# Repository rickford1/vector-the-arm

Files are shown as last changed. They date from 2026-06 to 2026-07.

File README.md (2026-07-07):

# Vector The Arm

Open-source 5-DOF printable robotic arm with vision-guided pick-and-place. Built on Feetech STS bus servos, ROS 2, MoveIt, and an Intel RealSense depth camera.

> **Status:** Work in progress. Mechanical assembly is complete (5-DOF arm +
> gripper). **All six servos are calibrated** and mirror live into RViz, and
> **MoveIt plans and executes on both the simulated and the real arm** — wrist
> roll and gripper included. Perception is not yet integrated.

## Features

- **5-DOF kinematic chain** + gripper
- **Smart serial bus servos** (Feetech STS3215) with position + current sensing for force-aware gripping
- **ROS 2 + MoveIt** motion planning — runs in simulation *and* drives the real arm
- **Live RViz mirroring** of the physical arm from the servo bus
- **Depth-camera perception** via Intel RealSense for vision-guided picking (planned)
- **Fully 3D-printable** structural parts

## Visualize the URDF

Requires ROS 2 Humble and the joint-slider GUI (one-time install):

```bash
sudo apt install ros-humble-joint-state-publisher-gui
```

Build the description package once, then launch RViz with joint sliders:

```bash
source /opt/ros/humble/setup.bash
cd ros2
colcon build --packages-select vector_the_arm_description
source install/setup.bash
ros2 launch vector_the_arm_description display.launch.py
```

Joint limits in the URDF are the calibrated ranges from
[docs/calibration_chart.md](docs/calibration_chart.md). If you edit the
URDF, re-run `colcon build` before launching by package name.

## Mirror the real arm in RViz

`scripts/arm_gui.py` owns the serial bus, publishes live encoder positions as
`/joint_states` (using `calibration.yaml` for the per-joint encoder→radian
mapping), and launches `robot_state_publisher` + RViz so the model tracks the
physical arm in real time. It also gives you per-joint sliders and an E-stop.

```bash
source /opt/ros/humble/setup.bash
source ros2/install/setup.bash          # so RViz can launch by package name
python3 scripts/arm_gui.py
```

Set `port:` in `calibration.yaml` to your bus device (e.g. `/dev/ttyACM0`).
Move the arm by hand (torque off) or drive joints from the GUI — RViz mirrors it.

## Motion planning with MoveIt

One-time install of MoveIt and ros2_control:

```bash
sudo apt install ros-humble-moveit ros-humble-ros2-control ros-humble-ros2-controllers
```

Build the MoveIt config once:

```bash
source /opt/ros/humble/setup.bash
cd ros2
colcon build --packages-select vector_the_arm_moveit_config
source install/setup.bash
```

### Simulation (mock hardware)

```bash
ros2 launch vector_the_arm_moveit_config demo.launch.py
```

Plans and executes against a simulated arm — no hardware needed. Good for
trying plans before running them on the real servos.

MoveIt has two planning groups: **`arm`** (Joint1–5) positions the wrist, and
**`Gripper`** (gripper_joint) opens/closes the jaw independently.

### Drive the real arm

`scripts/moveit_servo_bridge.py` is a `FollowJointTrajectory` action server that
replaces the mock hardware: it owns the serial bus, publishes `/joint_states`
from live encoder reads (so MoveIt's start state matches the real arm), and
streams planned trajectories to the servos — mapping radians→encoder and
**clamping every goal to each joint's `soft_min`/`soft_max`** via
`calibration.yaml`.

Run in two terminals, both with ROS + workspace sourced, arm powered:

```bash
# Terminal 1 — bridge (start first; takes the bus, enables torque holding the
# current pose, publishes joint states, serves the trajectory action)
python3 scripts/moveit_servo_bridge.py

# Terminal 2 — MoveIt (rsp + move_group + RViz, no mock hardware)
ros2 launch vector_the_arm_moveit_config bringup_real.launch.py
```

In the **MotionPlanning** panel the start state already matches the real arm.
Set a goal (Joints tab), **Plan**, then **Execute** — the servos follow.

**Safety:**
- Start with **Velocity Scaling 0.10** and small joint moves.
- Goals are clamped to soft limits, so a plan can't drive into a hard stop.
- **Ctrl+C the bridge terminal is the E-stop** — it disables torque on exit.

**Gripper on hardware:** the bridge serves a second `FollowJointTrajectory`
action for `Gripper_controller` (`gripper_joint`), so the **`Gripper`** planning
group opens/closes the real jaw too. Grip force is bounded by the servo torque
limit (addr 48) — set it with `scripts/set_torque_limit.py` before gripping
objects so a closed jaw doesn't overload the servo.

**5-DOF note:** the arm has 5 actuated joints (base yaw + 3 pitch + wrist roll) —
still under 6, so arbitrary full pose goals may not solve. Use **joint-space** or
**position-only** goals.

**Regenerating the MoveIt config:** the Setup Assistant writes integer values
into `config/joint_limits.yaml` (move_group needs doubles, e.g. `2.0`) and omits
`action_ns: follow_joint_trajectory` on controllers — fix both after generating
or move_group won't start / finds "0 controllers".

## Documentation

- [CALIBRATION.md](CALIBRATION.md) — end-to-end servo calibration procedure

## Repo layout

```
scripts/    Servo SDK tools, calibration utilities (incl. grip-force limiter
            set_torque_limit.py), manual-control + live-mirror GUI, and the
            MoveIt→Feetech trajectory bridge
ros2/       ROS 2 packages:
              vector_the_arm_description   URDF, meshes, display launches
              vector_the_arm_moveit_config MoveIt config (SRDF, controllers,
                                           demo + real-hardware bringup)
docs/       Reference data (calibration chart, per-joint parameters)
cad/        CAD source files (forthcoming)
```

## License

TBD

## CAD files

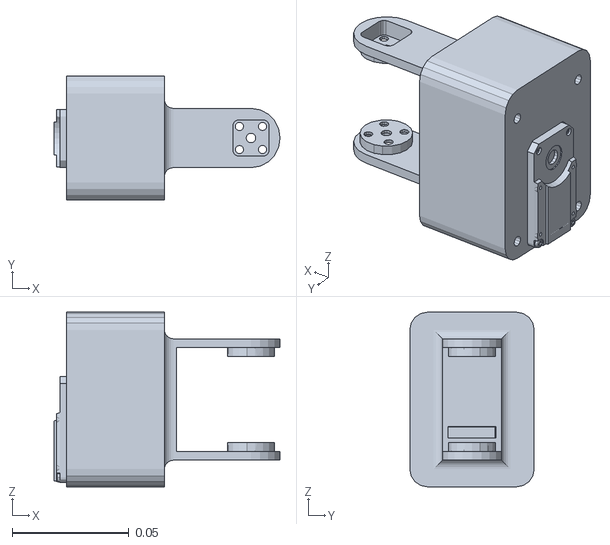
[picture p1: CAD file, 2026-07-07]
ros2/src/vector_the_arm_description/meshes/Link4.STL
0.0969 x 0.0533 x 0.0749

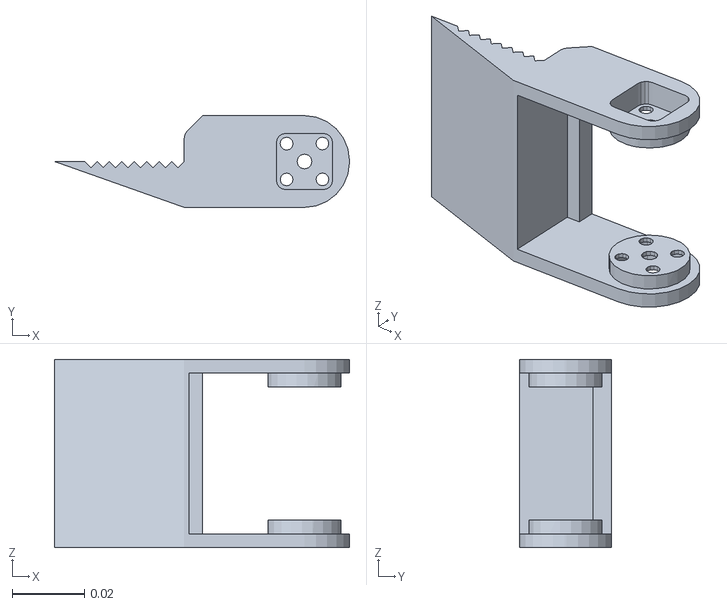
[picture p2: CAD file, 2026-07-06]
ros2/src/vector_the_arm_description/meshes/gripper.STL
0.0816 x 0.0254 x 0.0521

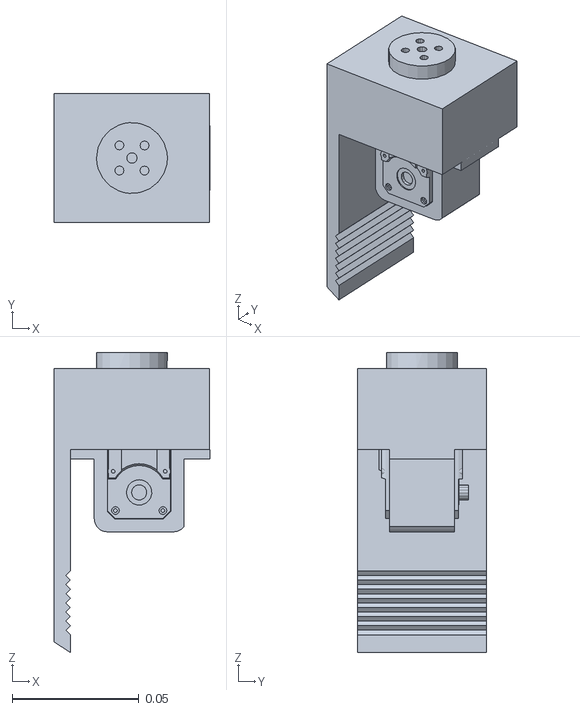
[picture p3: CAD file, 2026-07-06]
ros2/src/vector_the_arm_description/meshes/Link5.STL
0.0612 x 0.0508 x 0.118

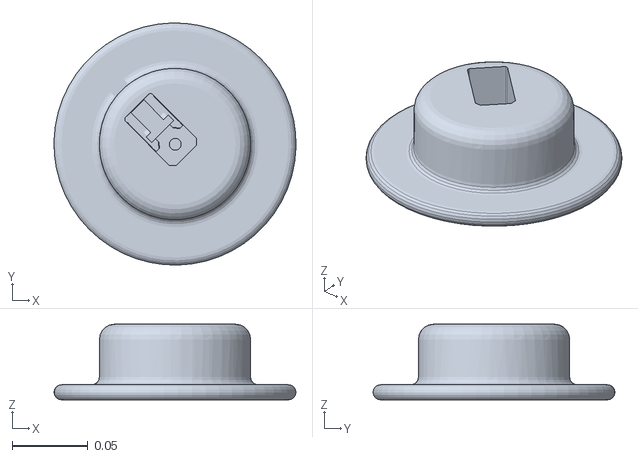
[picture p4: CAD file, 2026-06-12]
ros2/src/vector_the_arm_description/meshes/base_link.STL
0.16 x 0.16 x 0.05

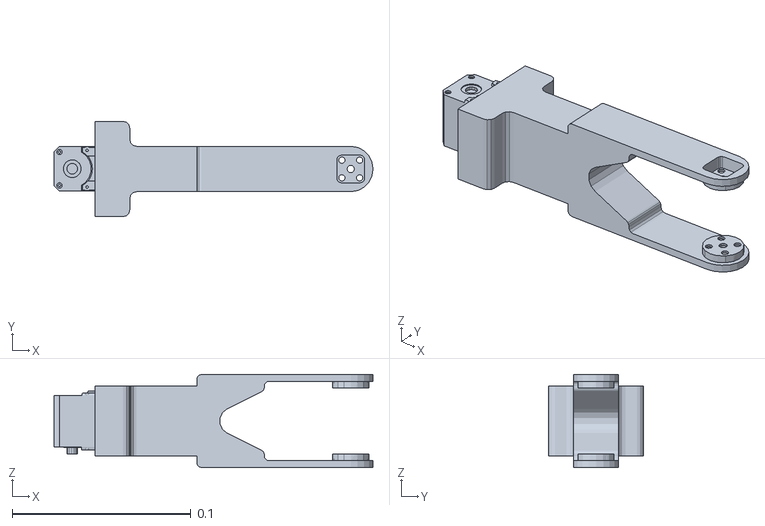
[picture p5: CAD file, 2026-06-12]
ros2/src/vector_the_arm_description/meshes/Link3.STL
0.179 x 0.0533 x 0.0521

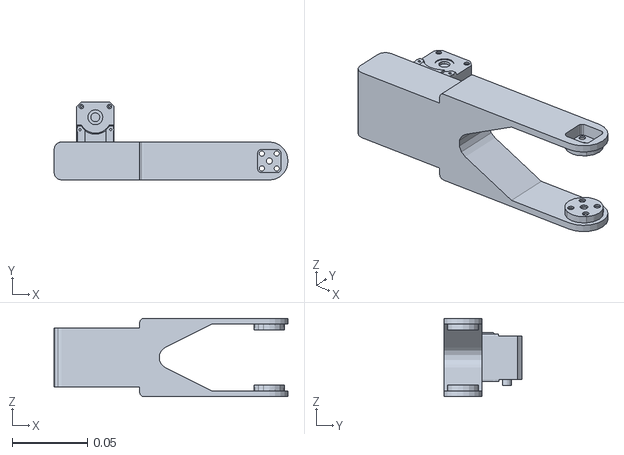
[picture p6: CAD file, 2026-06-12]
ros2/src/vector_the_arm_description/meshes/Link2.STL
0.156 x 0.052 x 0.0521

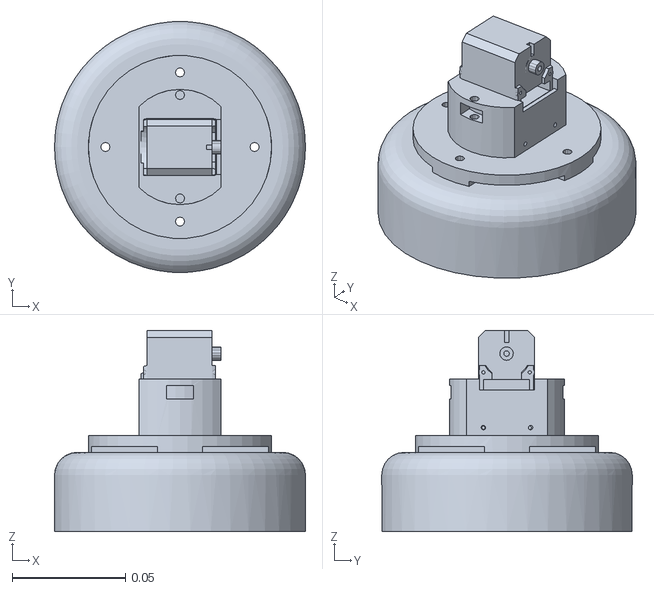
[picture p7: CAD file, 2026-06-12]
ros2/src/vector_the_arm_description/meshes/Link1.STL
0.111 x 0.111 x 0.0889

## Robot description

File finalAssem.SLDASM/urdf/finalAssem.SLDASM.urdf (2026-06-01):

<?xml version="1.0" encoding="utf-8"?>
<!-- This URDF was automatically created by SolidWorks to URDF Exporter! Originally created by Stephen Brawner (brawner@gmail.com) 
     Commit Version: 1.6.0-1-g15f4949  Build Version: 1.6.7594.29634
     For more information, please see http://wiki.ros.org/sw_urdf_exporter -->
<robot name="finalAssem.SLDASM">
  <link name="base_link">
    <inertial>
      <origin xyz="0.04017 0.036228 0.089961" rpy="0 0 0" />
      <mass value="0.47301" />
      <inertia ixx="0.00060925" ixy="-6.5656E-06" ixz="-2.5475E-09" iyy="0.00099286" iyz="2.1203E-09" izz="0.00059369" />
    </inertial>
    <visual>
      <origin xyz="0 0 0" rpy="0 0 0" />
      <geometry>
        <mesh filename="package://finalAssem.SLDASM/meshes/base_link.STL" />
      </geometry>
      <material name="">
        <color rgba="1 1 1 1" />
      </material>
    </visual>
    <collision>
      <origin xyz="0 0 0" rpy="0 0 0" />
      <geometry>
        <mesh filename="package://finalAssem.SLDASM/meshes/base_link.STL" />
      </geometry>
    </collision>
  </link>
  <link name="Link1">
    <inertial>
      <origin xyz="0 0 0.021148" rpy="0 0 0" />
      <mass value="0.078819" />
      <inertia ixx="0.00010458" ixy="0" ixz="-5.3187E-21" iyy="0.00010458" iyz="-1.4648E-20" izz="0.00019044" />
    </inertial>
    <visual>
      <origin xyz="0 0 0" rpy="0 0 0" />
      <geometry>
        <mesh filename="package://finalAssem.SLDASM/meshes/Link1.STL" />
      </geometry>
      <material name="">
        <color rgba="1 1 1 1" />
      </material>
    </visual>
    <collision>
      <origin xyz="0 0 0" rpy="0 0 0" />
      <geometry>
        <mesh filename="package://finalAssem.SLDASM/meshes/Link1.STL" />
      </geometry>
    </collision>
  </link>
  <joint name="Joint1" type="revolute">
    <origin xyz="0.039158 -0.09063 0.038393" rpy="0 0 0.78837" />
    <parent link="base_link" />
    <child link="Link1" />
    <axis xyz="0 0 0" />
    <limit lower="0" upper="0" effort="0" velocity="0" />
  </joint>
  <link name="Link2">
    <inertial>
      <origin xyz="0.049091 0.01203 -0.022092" rpy="0 0 0" />
      <mass value="0.089999" />
      <inertia ixx="2.8107E-05" ixy="-1.8894E-06" ixz="3.2642E-07" iyy="0.0001335" iyz="-9.2084E-08" izz="0.00011537" />
    </inertial>
    <visual>
      <origin xyz="0 0 0" rpy="0 0 0" />
      <geometry>
        <mesh filename="package://finalAssem.SLDASM/meshes/Link2.STL" />
      </geometry>
      <material name="">
        <color rgba="1 1 1 1" />
      </material>
    </visual>
    <collision>
      <origin xyz="0 0 0" rpy="0 0 0" />
      <geometry>
        <mesh filename="package://finalAssem.SLDASM/meshes/Link2.STL" />
      </geometry>
    </collision>
  </link>
  <joint name="Joint2" type="revolute">
    <origin xyz="-0.023218 0.012518 0.21186" rpy="3.1416 1.5708 0" />
    <parent link="Link1" />
    <child link="Link2" />
    <axis xyz="0 0 0" />
    <limit lower="0" upper="0" effort="0" velocity="0" />
  </joint>
  <link name="Link3">
    <inertial>
      <origin xyz="0.042349 0.012701 -0.022133" rpy="0 0 0" />
      <mass value="0.10792" />
      <inertia ixx="3.8564E-05" ixy="2.0743E-08" ixz="4.1708E-07" iyy="0.00015487" iyz="6.9966E-10" izz="0.00014301" />
    </inertial>
    <visual>
      <origin xyz="0 0 0" rpy="0 0 0" />
      <geometry>
        <mesh filename="package://finalAssem.SLDASM/meshes/Link3.STL" />
      </geometry>
      <material name="">
        <color rgba="1 1 1 1" />
      </material>
    </visual>
    <collision>
      <origin xyz="0 0 0" rpy="0 0 0" />
      <geometry>
        <mesh filename="package://finalAssem.SLDASM/meshes/Link3.STL" />
      </geometry>
    </collision>
  </link>
  <joint name="Joint3" type="revolute">
    <origin xyz="-0.11579 0.029138 0.00049896" rpy="0 0 0" />
    <parent link="Link2" />
    <child link="Link3" />
    <axis xyz="0 0 0" />
    <limit lower="0" upper="0" effort="0" velocity="0" />
  </joint>
  <link name="Link4">
    <inertial>
      <origin xyz="0.079969 0.012699 -0.019217" rpy="0 0 0" />
      <mass value="0.14858" />
      <inertia ixx="0.00010827" ixy="6.8754E-09" ixz="4.5551E-06" iyy="0.0001079" iyz="3.3593E-10" izz="7.5944E-05" />
    </inertial>
    <visual>
      <origin xyz="0 0 0" rpy="0 0 0" />
      <geometry>
        <mesh filename="package://finalAssem.SLDASM/meshes/Link4.STL" />
      </geometry>
      <material name="">
        <color rgba="1 1 1 1" />
      </material>
    </visual>
    <collision>
      <origin xyz="0 0 0" rpy="0 0 0" />
      <geometry>
        <mesh filename="package://finalAssem.SLDASM/meshes/Link4.STL" />
      </geometry>
    </collision>
  </link>
  <joint name="Joint4" type="revolute">
    <origin xyz="-0.15595 0.025556 -0.043973" rpy="3.1416 0 0" />
    <parent link="Link3" />
    <child link="Link4" />
    <axis xyz="0 0 0" />
    <limit lower="0" upper="0" effort="0" velocity="0" />
  </joint>
</robot>

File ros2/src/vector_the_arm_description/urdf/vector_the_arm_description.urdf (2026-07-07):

<?xml version="1.0" encoding="utf-8"?>
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
<robot name="vector_the_arm_description">
  <link name="base_link">
    <inertial>
      <origin xyz="0.0011876 -0.00024586 -0.0021651" rpy="0 0 0" />
      <mass value="0.47301" />
      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
    </inertial>
    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
  </link>
  <link name="Link1">
    <inertial>
      <origin xyz="-0.00013887 -3.7112E-05 0.037653" rpy="0 0 0" />
      <mass value="0.16671" />
      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
    </inertial>
    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
  </link>
  <joint name="Joint1" type="revolute">
    <origin xyz="0 0 0" rpy="0 0 3.1416" />
    <parent link="base_link" />
    <child link="Link1" />
    <axis xyz="0 0 1" />
    <limit lower="-1.5708" upper="1.5708" effort="3.0" velocity="2.0" />
  </joint>
  <link name="Link2">
    <inertial>
      <origin xyz="-0.09422 0.003695 -0.022118" rpy="0 0 0" />
      <mass value="0.12354" />
      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
    </inertial>
    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
  </link>
  <joint name="Joint2" type="revolute">
    <origin xyz="-0.023219 -0.000282 0.07716" rpy="3.1416 1.5708 0" />
    <parent link="Link1" />
    <child link="Link2" />
    <axis xyz="0 0 1" />
    <limit lower="-1.82" upper="1.82" effort="3.0" velocity="2.0" />
  </joint>
  <link name="Link3">
    <inertial>
      <origin xyz="-0.104627 -0.000063 -0.022151" rpy="0 0 0" />
      <mass value="0.14146" />
      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
    </inertial>
    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
  </link>
  <joint name="Joint3" type="revolute">
    <origin xyz="-0.11579 0.029138 0.00049896" rpy="0 0 0" />
    <parent link="Link2" />
    <child link="Link3" />
    <axis xyz="0 0 1" />
    <limit lower="-1.60" upper="1.60" effort="3.0" velocity="2.0" />
  </joint>
  <link name="Link4">
    <inertial>
      <origin xyz="-0.057402 -0.000135 -0.022293" rpy="0 0 0" />
      <mass value="0.18212" />
      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
    </inertial>
    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
  </link>
  <joint name="Joint4" type="revolute">
    <origin xyz="-0.15595 -0.000044 -0.043973" rpy="3.1416 0 0" />
    <parent link="Link3" />
    <child link="Link4" />
    <axis xyz="0 0 -1" />
    <limit lower="-1.55" upper="1.55" effort="3.0" velocity="2.0" />
  </joint>
  <link name="Link5">
    <inertial>
      <origin xyz="-0.0037812 -7.5442E-05 0.0098443" rpy="0 0 0" />
      <mass value="0.15471" />
      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
    </inertial>
    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
  </link>
  <joint name="Joint5" type="continuous">
    <origin xyz="-0.1347 -0.000286 -0.022559" rpy="1.5708 0 1.5708" />
    <parent link="Link4" />
    <child link="Link5" />
    <axis xyz="0 0 1" />
  </joint>
  <link name="gripper">
    <inertial>
      <origin xyz="-0.039632 -0.0052695 0.00073607" rpy="0 0 0" />
      <mass value="0.020259" />
      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
    </inertial>
    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
  </link>
  <joint name="gripper_joint" type="revolute">
    <origin xyz="0.002823 0 -0.008531" rpy="1.5708 -1.5708 0" />
    <parent link="Link5" />
    <child link="gripper" />
    <axis xyz="0 0 1" />
    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
    <limit lower="-0.468" upper="1.658" effort="1.0" velocity="1.0" />
  </joint>
</robot>

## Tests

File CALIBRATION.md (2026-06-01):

# Robot Arm Servo Calibration Guide

End-to-end calibration procedure for a Feetech STS3215-based robot arm. This is the procedure used to bring this arm from a box of parts to a fully-calibrated 5-DOF + gripper system ready for ROS 2 / MoveIt. Reading time ~15 min. Working time ~1–2 hours for a 4–6 joint arm.

## What "calibration" means here

For each servo, calibration produces four things stored in `calibration.yaml`:

1. **A unique bus ID** — so multi-drop bus addressing works
2. **A known horn orientation** — encoder pos 2048 corresponds to a known physical pose ("neutral")
3. **Mechanical range** — the encoder min/max for the joint's physical travel between hard stops
4. **Soft limits** — software-enforced bounds inside the mechanical range, with a safety margin

Plus, if needed: a **Position Correction** value written to EEPROM to fix encoder wraparound (when a joint's travel crosses encoder 0/4095).

The result: every script and ROS node in this project knows where each joint is in physical space and what range it can safely move through.

---

## Prerequisites

### Hardware

- Feetech STS3215 servos (any quantity; tested with 6)
- Waveshare bus servo driver board (or equivalent USB-to-TTL bus adapter)
- 12 V DC power supply, **≥5 A recommended** (10 A for stalling margin)
- USB cable to driver board
- Servos pre-assembled into arm (or bench setup if pre-assembly)

### Software

```bash
pip install feetech-servo-sdk pyyaml
```

This project uses the lower-level `protocol_packet_handler` API (the higher-level `sms_sts` class is not in the PyPI package — don't try to import it).

### Permissions

You'll need access to the serial device:

```bash
sudo usermod -a -G dialout $USER
# log out and back in
```

Otherwise, every script will fail with permission errors on `/dev/ttyACM*`.

### Find your bus device

```bash
ls /dev/ttyACM* /dev/ttyUSB*
```

Most setups show `/dev/ttyACM0`. The Waveshare board uses USB CDC-ACM, so it's `ttyACM*`, not `ttyUSB*`. **Note**: the number can shuffle between reboots — see [Troubleshooting → Port Shuffling](#port-shuffling) for a permanent fix.

### ⚠️ Verify PSU voltage before any servo work

STS3215 absolute max is ~14 V. Some "12 V" supplies (especially adjustable lab supplies and cheap bricks) drift high. **Check with a multimeter before plugging in servos.** A 14+ V supply will damage servos over time.

---

## The procedure

### Phase 1 — Assign unique IDs (one servo at a time)

**Every Feetech servo ships with factory ID = 1.** Plugging multiple new servos onto the same bus causes ID collisions: both servos respond to every ping simultaneously, the protocol corrupts, and you get inconsistent or no responses.

**Always assign IDs one servo at a time on an otherwise empty bus.**

For each servo:

1. **Power down** the bus (turn off the 12 V supply for safety, even though it's not strictly required for ID changes)
2. **Disconnect all other servos** from the bus. Leave only the servo you're about to flash.
3. **Power on**, then run:
   ```bash
   python3 scripts/scan.py --port /dev/ttyACM0 --max-id 10
   ```
   Confirm: only ID 1 responds (the factory default of the lone servo).
4. **Flash to the target ID**:
   ```bash
   python3 scripts/servo_id_setup.py --port /dev/ttyACM0 --new-id <N>
   ```
   Where `<N>` is the desired ID (1–253). For an arm, use sequential IDs starting at 1 from base to gripper.
5. **Verify**:
   ```bash
   python3 scripts/scan.py --port /dev/ttyACM0 --max-id 10
   ```
   Should now show only ID `<N>`.
6. **Power down**, disconnect this servo, connect the next factory-fresh one, repeat.

After all servos are flashed: power down, connect the full daisy chain (or split across both ports if your bus board has two), power up, and run the full scan. You should see every assigned ID respond.

> **If you see a collision** (servos showing intermittently or missing): one of your servos is at the same ID as another. Disconnect the most recently added one and the original should reappear. See [Troubleshooting → Bus collision recovery](#bus-collision-recovery).

> **If you accidentally renamed the wrong servo** (very easy mistake): the script defaults to `--current-id 1`. If you ran it on a populated bus, the script targeted whichever servo was at ID 1 — often the wrong one. Recover by disconnecting all but the renamed servo, identifying its current ID with `scan.py`, then using `--current-id <wrong_id> --new-id <correct_id>` to rename it back.

### Phase 2 — Mount horns at the calibration reference position

For each servo, we want **encoder pos 2048** (the middle of the encoder's 0–4095 range) to correspond to a known physical pose — usually the midpoint of the joint's mechanical travel for a bounded joint, or "facing forward" for a continuous-rotation base joint.

This isn't pixel-perfect: STS3215 has a 25-tooth output spline (~14.4° between mountable horn positions), so you'll mount as close as the spline allows and absorb the remaining offset in software.

For each servo:

1. **Drive to encoder pos 2048** with torque holding:
   ```bash
   python3 scripts/set_pos.py --port /dev/ttyACM0 --id <N> --pos 2048
   ```
   The script keeps torque on after the move so the shaft stays put while you align the horn.

2. **Mount the horn** at the closest spline position to the desired physical neutral. For a bounded joint, eyeball/measure the midpoint between the two mechanical hard stops. For the base joint (continuous), pick a "facing forward" or "joint angle 0" orientation that matches your kinematic convention.

3. **Tighten the horn screw firmly** before releasing torque — a loose horn slips under load, shifting your calibration.

4. **Release torque**:
   ```bash
   python3 scripts/relax.py --id <N>
   ```

5. Optionally photograph each horn orientation for future reference.

> For an arm assembled around already-mounted servos, you can skip this phase if the horns are already at sensible positions — Phase 3 (range capture) and Phase 4 (correction) handle any offset in software.

### Phase 3 — Capture mechanical range per joint

With horns mounted and the arm assembled, capture each joint's mechanical limits by hand-rotating between its hard stops:

For each joint:

1. **Release torque** (so you can rotate by hand):
   ```bash
   python3 scripts/relax.py --id <N>
   ```

2. **Start the recorder**:
   ```bash
   python3 scripts/range_record.py --port /dev/ttyACM0 --id <N>
   ```

3. **Hand-rotate the joint deliberately**:
   - Slowly to one hard stop, pause for ~1 second
   - Slowly back through center to the other hard stop, pause for ~1 second
   - Slowly to center

4. **Press Ctrl+C** to print the summary.

The summary shows `min`, `max`, `range`, and `center` in encoder steps and degrees.

> **Continuous-rotation joints** (e.g., base joints with slip rings or no hard stops): the recorded "range" will be ~360° because the joint can spin freely. Note these as `type: continuous` in `calibration.yaml`, and define software soft limits (typically ±180° from your chosen zero) to prevent wire twist.

### Phase 4 — Fix encoder wraparound (when needed)

If `range_record.py` reports a range close to **360° (min near 0, max near 4095)** on a joint that **physically cannot rotate that much**, the joint's mechanical range is crossing the encoder's 0↔4095 boundary. The encoder counts up to 4095, wraps to 0, and continues — making the recording show the full 0–4095 span even though the actual physical travel is smaller.

The fix: shift the encoder's reading via the **Position Correction register** (EEPROM addr 31) so the joint's range fits cleanly within 0–4095.

For each affected joint:

1. **Hand-rotate the joint to its physical midpoint** between the two hard stops (by feel, no software needed).

2. **Run the correction**:
   ```bash
   python3 scripts/set_correction.py --port /dev/ttyACM0 --id <N> --target 2048
   ```
   This reads the current encoder value, computes the offset needed to make this pose read 2048, and writes it to EEPROM. You'll be prompted to confirm (type `y`).

3. **Re-run `range_record.py`** to verify a clean range:
   ```bash
   python3 scripts/range_record.py --port /dev/ttyACM0 --id <N>
   ```
   Should now show a sensible physical range (e.g. 1029–3059, ~178°) with `min` and `max` both well clear of 0 and 4095.

> **Critical rule**: only run `set_correction.py` when wraparound is *actually present*. If `range_record.py` already shows a clean range, do not run it — applying an unnecessary correction can create a wraparound where there wasn't one.

### Phase 5 — Save the calibration data

Update `calibration.yaml` with each joint's results. Template:

```yaml
port: /dev/ttyACM0
baud: 1000000

servos:
  - id: 1
    joint_name: base
    type: continuous           # or "bounded" for joints with hard stops
    encoder_min: 0             # for continuous, use full encoder range
    encoder_max: 4095
    encoder_center: 2048       # from range_record summary
    soft_min: 1024             # for continuous, set ±90° from center initially
    soft_max: 3072
    position_correction: 0     # if no correction was applied
    direction: 1               # +1 or -1, depending on URDF convention
    model: 777
    notes: continuous rotation; soft-limited to ±90° to avoid wire twist

  - id: 2
    joint_name: joint2
    type: bounded
    encoder_min: 902           # from range_record "min"
    encoder_max: 3280          # from range_record "max"
    encoder_center: 2091       # from range_record "center"
    soft_min: 952              # add 50-step margin from hard stops
    soft_max: 3230
    position_correction: -1937 # informational; actual value lives in servo EEPROM
    direction: 1
    model: 2825                # firmware variants exist; harmless
    notes: 209° range
```

The `soft_min` / `soft_max` values are what the GUI and ROS bridge use as bounds. Default to a ~50-step margin (~4°) inside the hard stops to prevent driving the joint into a physical stop under torque.

### Phase 6 — Verify with the GUI

```bash
python3 scripts/arm_gui.py
```

A window opens with one row per servo: live position display, slider bounded by soft limits, per-joint torque toggle, and global E-STOP. For each calibrated joint:

1. **Enable torque** via the checkbox
2. **Move the slider** slowly — the joint should smoothly track the slider value
3. **Watch the live position** — should match the slider value within a few steps
4. **Try the endpoints** of the slider — joint should reach near the soft limits without straining
5. **Hit E-STOP** at any point to release torque on all joints

If a joint strains, fights the slider, or refuses to move, see [Troubleshooting](#troubleshooting).

When you close the window, all torque is released automatically.

---

## Troubleshooting

### Port shuffling

The `/dev/ttyACM*` number can change between reboots (e.g., `ttyACM0` becomes `ttyACM2`). Permanent fix via a udev rule:

1. Find the board's USB IDs:
   ```bash
   udevadm info -a -n /dev/ttyACM0 | grep -E 'idVendor|idProduct' | head -4
   ```

2. Create `/etc/udev/rules.d/99-feetech.rules`:
   ```
   SUBSYSTEM=="tty", ATTRS{idVendor}=="XXXX", ATTRS{idProduct}=="YYYY", SYMLINK+="feetech-bus", MODE="0666"
   ```

3. Reload:
   ```bash
   sudo udevadm control --reload-rules
   sudo udevadm trigger
   ```

Now `/dev/feetech-bus` always points to your board. Set `port: /dev/feetech-bus` in `calibration.yaml`.

### Bus collision recovery

If two servos end up at the same ID, neither will respond cleanly (both try to answer every ping → protocol corruption → timeout).

1. **Disconnect one of the colliding servos** physically — usually the one you most recently added.
2. **Scan the remaining bus**:
   ```bash
   python3 scripts/scan.py --port /dev/ttyACM0 --max-id 10
   ```
   The remaining servo should now respond at the disputed ID.
3. **Rename it** to its proper ID:
   ```bash
   python3 scripts/servo_id_setup.py --port /dev/ttyACM0 --current-id <wrong> --new-id <correct>
   ```
4. **Reconnect the other servo** alone on the bus (without the first one) and flash it to its correct ID.
5. **Reconnect everything**, scan again to verify.

### Voltage error (status byte = 1)

If `diag.py` reports `Status byte: 1 ['voltage']`, the servo's firmware detected over-voltage. Check the PSU output with a multimeter:

- Should read **12.0 V ± 0.3 V**
- 13 V or higher: dial down the supply (if adjustable) or replace it (if fixed). 14+ V will damage servos cumulatively.

### Joint strains / moves slowly

This happens when the servo is fighting a load it doesn't have enough torque for — common on base joints supporting the full arm mass. Distinguish from a faulty servo:

1. **Run `diag.py`** — verify Mode is 0 (position), torque limit is 1000/1000, status byte is 0 (no errors)
2. **Bench-test off the arm**: unbolt the servo and run `nudge.py` with no load
   - If it moves cleanly → arm load is the issue (mechanical, not the servo)
   - If it still strains → real servo issue (gear damage, low PSU current, voltage sag under load)

Common arm-load fixes: lighter end-effector, more PSU current capacity, mechanical advantage in design (gear reduction, counterbalance).

### "No response" on a known-good servo

- **Power cycle the 12 V supply** — servo firmware can hang
- **Verify the bus connection** — daisy-chain connectors are easy to dislodge
- **Try a different baud** with `scan.py` — defaults to 1 Mbaud but factory or modified servos may be different

---

## Script reference

| Script | Purpose | Modifies hardware? |
|---|---|---|
| `scan.py` | Sweep IDs at all common baud rates, list found servos | Read-only |
| `status.py` | Show position / voltage / temperature for given IDs | Read-only |
| `diag.py` | Full per-servo state snapshot | Read-only |
| `servo_id_setup.py` | Change a servo's bus ID (EEPROM write) | Yes — EEPROM |
| `set_pos.py` | Drive a servo to a target encoder position, keeps torque on | Yes — torque + motion |
| `nudge.py` | Small relative move from current position | Yes — torque + motion |
| `relax.py` | Disable torque on one or many servos | Yes — torque off |
| `range_record.py` | Disable torque, log min/max during hand rotation | Yes — torque off |
| `set_correction.py` | Write Position Correction register (EEPROM) to shift encoder readout | Yes — EEPROM |
| `arm_gui.py` | Interactive GUI for manual joint control within soft limits | Yes — torque + motion (user-controlled) |

All scripts accept `--port <device>` (default `/dev/ttyACM0`) and `--id <N>` where applicable. Run any with `--help` for full argument list.

---

## What's next

After calibration is complete and verified with the GUI:

1. **Build the URDF** from your CAD assembly (or the included `urdf/` files if cloning this repo)
2. **Build the ROS 2 bridge node** that translates between `sensor_msgs/JointState` topics and the Feetech bus, using `calibration.yaml` for per-joint scale/offset/limits
3. **Integrate with MoveIt** for motion planning
4. **Add perception** (e.g., RealSense + object detection) for vision-guided tasks

Each of these is covered in separate guides (`URDF.md`, `ROS2_BRIDGE.md`, `MOVEIT.md`, `PERCEPTION.md`). The calibration data you generated here flows through all of them.

---

## Open questions / known caveats

- **Continuous-rotation joints** need software multi-turn tracking if you want to count revolutions, or soft limits at ±180° to avoid wraparound during operation.
- **Position Correction values are informational in `calibration.yaml`** — the actual correction lives in servo EEPROM. Editing the YAML doesn't change the servo's behavior; use `set_correction.py` to update it.
- **Direction sign per joint** is left as `TBD` until the URDF is built — it depends on your kinematic frame conventions. Easily flipped later in `calibration.yaml`.
- **Motor mass for accurate dynamics**: STS3215 datasheet says ~60 g. For Gazebo simulation or dynamics-aware planning, override mass in your CAD before exporting the URDF; the raw STEP file usually computes wrong from solid-density math.

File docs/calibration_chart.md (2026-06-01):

# Servo Calibration

Reference pos: `2048` (encoder midpoint) for all servos.
Bus: `/dev/ttyACM0`, baud `1000000`, protocol STS.

## Per-servo calibration

| ID | Joint | Model | Range type | Mounted at | Min (steps) | Max (steps) | Range (steps) | Range (deg) | Mech midpoint (steps) | Offset from 2048 | Direction | Notes |
|----|---|---|---|---|---|---|---|---|---|---|---|---|
| 1  | base | 777  | continuous | 2048 | n/a | n/a | n/a | n/a | 2044 (centered) | -4 | TBD | **continuous rotation — no hard stops**. Horn well-centered (offset -4). Need software multi-turn tracking or soft limits at e.g. ±180° from 2048. |
| 2  | (joint?) | 2825 | 209° | 2048 | 902 | 3280 | 2378 | 209.0 | 2091 | +43 | TBD | model 2825 variant. Position Correction set via set_correction.py; raw was crossing 0/4095 boundary |
| 3  | (joint?) | 777  | 183° | 2048 | 981 | 3064 | 2083 | 183.1 | 2022 | -26 | TBD | recalibrated post-reassembly; existing Position Correction retained; clean range |
| 4  | joint4 | 777  | 178° | 2048 | 1029 | 3059 | 2030 | 178.4 | 2044 | -4 | TBD | additional arm joint; clean range, Position Correction set |
| 5  | wrist_roll | 777  | TBD  | TBD  | --- | --- | --- | --- | --- | --- | TBD | new servo, ID flashed; bare on bench; calibrate when wrist roll module is built |
| 6  | gripper | TBD  | TBD  | TBD  | --- | --- | --- | --- | --- | --- | TBD | not yet purchased; will be 6th servo |

## Field meanings

- **Mounted at**: encoder pos the horn was aligned at during calibration (always 2048 here)
- **Min / Max (steps)**: encoder values at each mechanical hard stop, captured via `range_record.py`
- **Range (steps)**: max − min
- **Range (deg)**: range × (360 / 4096)
- **Mech midpoint (steps)**: (min + max) / 2 — the true physical midpoint, in encoder steps
- **Offset from 2048**: mech_midpoint − 2048 — how far the actual midpoint sits from the nominal reference. Goes into the per-joint software calibration as `encoder_zero`.
- **Direction**: +1 or -1 — sign of joint angle relative to increasing encoder position (decide per joint based on your URDF / right-hand-rule convention)

## Verification notes per servo

- **ID 1** — comms OK (model 777), bench-test clean unloaded. Strained when mounted under arm load (expected for base joint).
- **ID 2** — comms OK (model **2825** — variant), nudge ±17° clean (err -3 / +0).
- **ID 3** — comms OK (model 777), motion test deferred (was electrically pinned near top of range, only ~1° of room in mechanically-free direction).
- **ID 4** — comms OK (model 777), nudge -20° clean (err +15 / -1).

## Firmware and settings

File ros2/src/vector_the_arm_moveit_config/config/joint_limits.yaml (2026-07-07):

# joint_limits.yaml allows the dynamics properties specified in the URDF to be overwritten or augmented as needed

# For beginners, we downscale velocity and acceleration limits.
# You can always specify higher scaling factors (<= 1.0) in your motion requests.  # Increase the values below to 1.0 to always move at maximum speed.
default_velocity_scaling_factor: 0.1
default_acceleration_scaling_factor: 0.1

# Specific joint properties can be changed with the keys [max_position, min_position, max_velocity, max_acceleration]
# Joint limits can be turned off with [has_velocity_limits, has_acceleration_limits]
joint_limits:
  Joint1:
    has_velocity_limits: true
    max_velocity: 2.0
    has_acceleration_limits: false
    max_acceleration: 0.0
  Joint2:
    has_velocity_limits: true
    max_velocity: 2.0
    has_acceleration_limits: false
    max_acceleration: 0.0
  Joint3:
    has_velocity_limits: true
    max_velocity: 2.0
    has_acceleration_limits: false
    max_acceleration: 0.0
  Joint4:
    has_velocity_limits: true
    max_velocity: 2.0
    has_acceleration_limits: false
    max_acceleration: 0.0
  Joint5:
    has_velocity_limits: false
    max_velocity: 0.0
    has_acceleration_limits: false
    max_acceleration: 0.0
  gripper_joint:
    has_velocity_limits: true
    max_velocity: 1.0
    has_acceleration_limits: false
    max_acceleration: 0.0

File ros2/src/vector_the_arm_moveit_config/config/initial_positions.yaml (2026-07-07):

# Default initial positions for vector_the_arm_description's ros2_control fake system

initial_positions:
  Joint1: 0
  Joint2: 0
  Joint3: 0
  Joint4: 0
  Joint5: 0
  gripper_joint: 0

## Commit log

2026-06-01 Add finalAssem.SLDASM URDF package
    [Link1.STL, Link2.STL, Link3.STL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]
2026-06-01 Rename package to vector_the_arm_description (ROS-valid name)
    [vector_the_arm_description.csv, vector_the_arm_description.urdf]
2026-06-01 create proper folder and repo structure along with refactor for improved readability
    [Link1.STL, Link2.STL, Link3.STL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]
2026-06-12 improve readme and update the urdf to better represent the cad
    [Link1.STL, Link2.STL, Link3.STL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]
2026-06-12 update urdf and cad stl files to include motor positions
    [Link1.STL, Link2.STL, Link3.STL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]
2026-07-02 update joint state publisher and gui to run with simulated model and physical model at the same time WIP
    [calibration.yaml, vector_the_arm_description.urdf]
2026-07-02 integrate moveit configuration for simulated enviorment
    [joint_limits.yaml, ros2_controllers.yaml, vector_the_arm_description.ros2_control.xacro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]
2026-07-06 Add MoveIt servo bridge and YOLO object detection scripts
    - Introduced `bringup_real.launch.py` to launch MoveIt with real hardware.
    - Added `moveit_servo_bridge.py` to interface with Feetech servos, handling joint states and trajectory execution.
    - Implemented `yolo_detect.py` for real-time object detection using YOLO on RealSense camera feed.
    - Included YOLOv8n model file for object detection capabilities.
    [Link5.STL, gripper.STL]
2026-07-07 Added torque limit script and finished calibration for servo 5 and 6 - next step to integrate object detection
    [Link4.STL, calibration.yaml, vector_the_arm_description.urdf]
2026-07-07 update readme improve gripper support
    [calibration.yaml, joint_limits.yaml, ros2_controllers.yaml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]
2026-07-07 add action server for gripper control and update torque limit handling in documentation
    [calibration.yaml]
